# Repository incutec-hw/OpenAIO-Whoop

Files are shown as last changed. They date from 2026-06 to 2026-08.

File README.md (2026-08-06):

# OpenAIO-Whoop

Open-source whoop-class AIO board with a 25.5 x 25.5 mm mounting pattern, part of the incutec OpenDrone line. One board combines an RP2354A flight controller (LSM6DSV16X IMU, Betaflight custom target), four Bluejay (EFM8BB51) brushless ESC channels on an XR8G02M direct-drive P+N power stage, a serial ExpressLRS 2.4 GHz receiver (ESP32-C3 + SX1281) and a W25Q128JVPIQ 16 MB SPI NOR blackbox flash. Digital video only: SH1.0 6-pin HD-VTX port, no onboard analog VTX or OSD. Target class is 1S/2S whoops (65-85 mm). Designed in KiCad 10.

Full specification, part-level detail (LCSC numbers, power stage rationale, second sources) and current design state: [hardware/docs/DESIGN.md](hardware/docs/DESIGN.md).

## Status

**Prototype pending**, early design, 2026-08-05.
Forked from OpenAIO and being adapted for whoop class. FC and RX schematic sheets are imported from sibling designs and ESC parts are selected, but the ESC channel sheet and the board layout still carry the inherited donor design. Sheet-by-sheet state: [Design state](hardware/docs/DESIGN.md#design-state).

## Repository layout

| Path | Contents |
|---|---|
| `hardware/` | KiCad 10 project: top sheet, sub-sheets, project-local libraries |
| `hardware/docs/` | Design documentation ([DESIGN.md](hardware/docs/DESIGN.md), [ESC_DESIGN.md](hardware/docs/ESC_DESIGN.md), [MARKET-RESEARCH-2026-06.md](hardware/docs/MARKET-RESEARCH-2026-06.md)) |
| `libs/KiCad-Library` | Shared Incutec symbol/footprint/3D library (git submodule) |

## Design entry points

- Top schematic: `hardware/OpenAIO-Whoop.kicad_sch`
- FC sheets: `hardware/schematics/fc/` (rp2350a, power, imu, blackbox, pads; from OpenFC-Lite-Mini rev 2, no OSD sheet)
- ESC sheet: `hardware/schematics/esc/esc_channel.kicad_sch`, instantiated 4 times
- RX sheet: `hardware/schematics/elrs/elrs.kicad_sch` (OpenRX-Lite)
- Board: `hardware/OpenAIO-Whoop.kicad_pcb`

Project-local libraries: `hardware/lib.*` (FC), `hardware/whoop.*` (Bluejay ESC parts), `hardware/components.kicad_sym` with `hardware/4in1ESC.pretty` (ESC donor parts), `hardware/OpenRX-Shared.*` (RX). The project lib tables also reference the shared `Incutec` library from the `libs/KiCad-Library` submodule, used for new parts; KiCad standard libraries are the only other external references.

## Build and export

```
git clone --recursive https://github.com/incutec-hw/OpenAIO-Whoop.git
```

Open `hardware/OpenAIO-Whoop.kicad_pro` in KiCad 10. Production exports (gerbers, BOM, CPL) are generated with the [KiCad Fabrication Toolkit](https://github.com/bennymeg/Fabrication-Toolkit) plugin into `hardware/production/` (gitignored). Headless checks use `kicad-cli`:

```
kicad-cli sch erc --exit-code-violations hardware/OpenAIO-Whoop.kicad_sch
kicad-cli pcb drc --exit-code-violations hardware/OpenAIO-Whoop.kicad_pcb
```

## Manufacturing

No production exports exist yet and no hardware has been fabricated.

## Contributing

See [CONTRIBUTING.md](CONTRIBUTING.md).

## License

Hardware licensed under [CERN-OHL-S-2.0](https://ohwr.org/cern_ohl_s_v2.txt). See [LICENSE](LICENSE). Referenced firmware projects (Betaflight, Bluejay, ExpressLRS) remain under their own upstream licenses.

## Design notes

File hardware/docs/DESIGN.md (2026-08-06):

# OpenAIO-Whoop Design Notes

Detailed design description of the OpenAIO-Whoop. The design is early stage: part selection is done, the ESC schematic and the whoop board layout are not. ESC topology research and sourcing history: [ESC_DESIGN.md](ESC_DESIGN.md). Competitive landscape: [MARKET-RESEARCH-2026-06.md](MARKET-RESEARCH-2026-06.md).

## Architecture

Three stages on one board with a 25.5 x 25.5 mm mounting pattern: flight controller, 4x brushless ESC, serial ExpressLRS 2.4 GHz receiver. Target class is 1S/2S whoops, 65-85 mm. Digital video only: an SH1.0 6-pin HD-VTX port, no analog VTX or OSD hardware.

| Stage | Basis | State |
|---|---|---|
| FC | OpenFC-Lite-Mini rev 2 sheets (RP2354A) | imported |
| ESC | New design: EFM8BB51 (Bluejay BB51) + XR8G02M direct-drive P+N power stage, SiA527DJ qualified second source | parts imported, schematic not drawn |
| RX | OpenRX-Lite (ESP32-C3 + SX1281, serial ELRS) | imported |

## Design state

- Pack voltage (1S vs 2S) is undecided. On top of the locked direct-drive P+N power stage, it decides the per-phase level-shift parts (2S adds a 2N7002 level shift per phase so the P-gate can reach VBAT) and the BEC topology (1S needs a boost to feed a DJI O4 Lite properly).
- ESC power stage is decided: XR8G02M, 2 x 2 mm complementary P+N, GPIO direct drive, no gate-driver IC, honest rating ~8 A continuous / 15-20 A burst per motor. The 12 A dual-N market tier is deliberately not pursued: dual-N needs high-side drive, excluded by the no-driver constraint. Earlier candidates (AGM310MAP, AGM314MAP, N+N plus driver) are superseded; full history in [ESC_DESIGN.md](ESC_DESIGN.md).
- Blackbox: W25Q128JVPIQ 16 MB SPI NOR replaces the microSD slot and the dead BY25Q64; the blackbox sheet still shows the microSD slot until redrawn.
- The ESC channel sheet (`esc_channel.kicad_sch`, instantiated 4x) still contains the inherited AT32/AM32 donor channel from the OpenESC lineage, not the EFM8BB51 + XR8G02M design.
- The board file (`OpenAIO-Whoop.kicad_pcb`) carries the inherited OpenAIO placement and routing, not a whoop layout. Its Edge.Cuts outline is still the donor 33 x 33 mm rounded rectangle around the 25.5 x 25.5 mm hole pattern; no whoop outline has been drawn.
- The 1.8 V gyro LDO on the inherited FC sheets, NCV8187 (effectively unobtainable), is replaced by TPS7A2018 (decided, imported); the sheets still show NCV8187.

## Key parts, Bluejay ESC (`whoop` library)

| Function | Part | LCSC | Note |
|---|---|---|---|
| ESC MCU x4 | EFM8BB51F16G-C-QFN20R (8051, 50 MHz) | C6547511 | Bluejay BB51 target; not in JLC assembly lib, verify or consign |
| Power stage | XR8G02M complementary N+P, DFN2020-8 (2 x 2 mm), x3 per channel, GPIO direct drive | C42457203 | 20 V, N 15 / P 25 mOhm max at 4.5 V (spec'd to 2.5 V), ~8 A cont / 15 A+ burst per motor. Single-source brand: reel-order up front. Second source: SiA527DJ (C222486) |
| 1.8 V gyro LDO | TPS7A2018PDQNR, X2SON-4 (1 x 1 mm) | C2878130 | 75 dB PSRR at 10k-100 kHz; LCSC stock thin, consign from DigiKey |
| Blackbox flash | W25Q128JVPIQ 128 Mbit SPI NOR, WSON-8 (5 x 6 mm) | C190862 | 16 MB is the market bar; replaces dead BY25Q64 |
| RX MCU option | ESP8685H4 (ESP32-C3 die, 4 MB flash), QFN-28 (4 x 4 mm) | C4944062 | 1 mm smaller each side than ESP32-C3FH4; same ELRS targets |

## Key parts, FC and RX (inherited from sibling designs)

RP2354A, LSM6DSV16XTR, 2x LMR51430, TPS2116, LP5912, NCV8187 (superseded by TPS7A2018, see above), TF-021B microSD (superseded by W25Q128JVPIQ, see above), ESP32-C3FH4 + SX1281 + TLV75533. Full part tables are in the [OpenAIO](https://github.com/incutec-hw/OpenAIO) repo.

## Firmware targets

| Stage | Target |
|---|---|
| FC | Betaflight, derived from `OPENFC_LITE_MINI_RP2350A` (custom target) |
| ESC x4 | Bluejay BB51, 48 kHz (2S) / 96 kHz (1S), bidirectional DShot |
| RX | ExpressLRS `Unified_ESP32C3_2400_RX` (survives in ELRS 4.0 targets) |

## Market reference

Class reference board: BetaFPV Matrix 1S 3IN1 HD. Its specification, the class bar it sets, the full whoop-class table and the verified 2025-2026 trends: [MARKET-RESEARCH-2026-06.md](MARKET-RESEARCH-2026-06.md).

## Revisions

- **2026-08-04**: shared Incutec KiCad library wired in as the `libs/KiCad-Library` submodule.
- **2026-06-12**: ESC part selection: XR8G02M power stage (SiA527DJ second source), no-gate-driver topology locked, W25Q128JVPIQ blackbox flash, TPS7A2018 gyro LDO. Repo restructured under `hardware/`; FC and RX sheets imported; Bluejay part libraries and research docs added.
- **2026-06-01**: forked from OpenAIO as the whoop-class variant.

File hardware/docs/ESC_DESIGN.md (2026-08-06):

# Bluejay ESC, topology and sourcing research

Research trail behind the OpenAIO-Whoop ESC stage: what was measured, what was rejected, and why. The current decisions and their LCSC numbers live in [DESIGN.md](DESIGN.md); this file keeps the comparisons that produced them and does not restate the final part table. Competitive landscape and the class bar this research measured against: [MARKET-RESEARCH-2026-06.md](MARKET-RESEARCH-2026-06.md).

Scope of the work: rework the inherited AT32F421 / NSG2065Q ESC into a Bluejay (EFM8BB51, BB51 target) design for a 1S/2S whoop-class AIO with integrated ELRS and a digital video connector. Library import is done; no schematic or PCB work has been performed yet.

## Topology: no gate-driver IC (locked, 2026-06-12)

**The Bluejay ESC has no gate-driver IC, EFM8 GPIO direct drive only, there is no board space for one.** That locks the power stage to a complementary P+N pair per phase, because a high-side N-channel is impossible without a driver or a bootstrap. Consequences:

- 1S: clean direct drive, zero extra parts (the CrazyBee / tinyPEPPER pattern, confirmed by the teardowns below).
- 2S: the P-gate must reach VBAT (8.4 V) to turn OFF, so each phase needs a discrete level shift (2N7002, C8545, a JLC basic part, plus a pull-up: about 2 parts per phase, 24 per board). That is the only no-driver-IC option. If even that is too much board space, the design is 1S-only.
- The 12 A dual-N market tier (BetaFPV SiZ322DT boards) is off the table, because dual-N needs high-side drive. Honest rating for this topology is ~6-8 A continuous per phase, which covers 65-75 mm 1S whoops (real currents <=5 A per motor), not the 12 A spec-sheet war.

### Gate drive research that led there

Verified: small Bluejay/BLHeli_S whoop ESCs (for example **tinyPEPPER**, open hardware) drive the FET gates directly from the EFM8, with no gate-driver IC. That is correct **for 1S only**:

- At 1S (<=4.2 V) the 3.3 V GPIO can turn the high-side P-channel both ON (Vgs about -4 V) and OFF (the gate can be pulled to pack voltage). The MCU runs straight off the 1S pack.
- At 2S (8.4 V) direct drive breaks down: the P-channel source sits at 8.4 V and a 3.3 V GPIO cannot pull the gate up to 8.4 V to switch the high side **off**. tinyPEPPER author: *"For 2S one needs FET drivers and a proper voltage regulator for the CPUs."*

Open points that follow:

- At 2S the EFM8 needs its own 3.3 V regulator; it cannot run off the pack directly (abs max ~4.2 V).
- The low-side N can still be GPIO-driven through a gate resistor at 2S (source at GND, 3.3 V against Vgs(th) 1.6 V). Verify enhancement is adequate, consider a buffer if marginal.
- Pick gate resistors from Qg and the desired edge rate (tinyPEPPER reference: ~100 Ohm for ~50 nC / 500 ns).
- Rejected alternative: a proper 3-phase gate driver IC, which is what the inherited NSG2065Q did. Most robust, biggest BOM, no board space.

## What commercial whoop ESCs actually use (teardown research, verified)

- **CrazyBee F4 V2 class (5-10 A 1S, the architecture we are copying)**: 12x N+P complementary pairs marked "EGX87C" (full MPN never decoded, sold as repair parts under the marking), **driven directly by EFM8 GPIO, no driver**.
- **NewBeeDrone BLV1-4 / Hummingbird V2/V3**: the official replacement part is "N+P MOS" x12, same topology, MPN undisclosed.
- **BetaFPV F4 1S 12A (2022)**: 12x Vishay SiZ322DT dual-N 25 V PowerPAK1212 (3.3 x 3.3), EOL at DigiKey (successor SiZ350DT ~$2). Teardown identifies roughly 3-pin 0402-size parts plus 3 Schottkys and 3 bootstrap caps per motor, so the undocumented high-side drive is a **discrete bootstrap level shift per phase**: about 3 extra parts per phase, 9 per motor, 36 per board. Not for us.
- **NBD BLV5 / RaceSpec V2 "18A"**: "double N-channel", MPN undisclosed.
- **20 A+ toothpick tier**: Toshiba TPN2R203NC-class discrete N plus FD6288 drivers, that is the OpenESC-20x20 architecture, irrelevant here.
- **2025 Matrix 1S 5IN1 II (Air65 II, "12A/18A")** uses AGMSEMI **AGM210MAP, complementary P+N, GPIO direct drive: the same architecture we chose.** Datasheet verified locally: PDFN 3.3 x 3.3 (not 2 x 2; note that LCSC and BetaFPV listings say 25 V while the datasheet says **20 V**), N 10 typ / 14 max mOhm at 4.5 V (14/20 at 2.5 V), P 13 mOhm typ, Vgs(th) max 1.0 V, 25 A / 100 A pulsed, RthJC 3.5. C7431169, 10,623 stock, 20x the stock of AGM310MAP or AGM314MAP.
- Bluejay layout naming note: the middle letter (Z_**H**_30, A_**X**_5) is the MCU family (H = BB21, X = BB51), NOT the FET topology; only the deadtime digits hint at the stage.

Implications of the Matrix 1S 5IN1 II teardown:

- The flagship "12A/18A" 1S board is P+N direct drive, so our topology is the current market architecture, not the legacy one. Their 12 A claim on N 10 / P 13 mOhm dies works out to about 1.7 W per phase: spec-sheet optimistic, and consistent with our honest-rating stance.
- **AGM210MAP supersedes AGM310MAP and AGM314MAP as the AGMSEMI pick at the 3.3 x 3.3 tier** (better dies, field-proven on the Air65 II, real stock). Earmarked for the mid-tier 2S Bluejay concepts, not for this board: its 20 V rating means a 2-3S ceiling.
- Why 20-25 V parts on a 1S board? Voltage class is nearly free in trench processes; it buys avalanche margin against phase-node inductive spikes and lets one part cover 1S to 2S+ product lines. XR8G02M (20 V) follows the same logic.
- Also on that board: G473CEU6 (we use RP2354A), BB51F16G QFN-20 (the same EFM8 as ours), AT7456E analog OSD plus an RTC6705-class VTX (not applicable, we are digital-only), PUYA PY25Q128 16 MB blackbox flash, and a **2-Schottky diode-OR for 5 V/USB selection** instead of a power-mux IC. The diode-OR is a candidate to replace TPS2116 on the whoop: saves space and cost, costs ~0.3 V drop, trade accepted.

## Power stage sweep

Requirement from the layout: the package must fit a whoop board, so <=2.2 x 2.2 mm. AGM314MAP (3.3 x 3.3) is too big for this board and stays earmarked for the larger AM32 toothpick AIO. A full LCSC sweep at <=2.2 x 2.2 found **exactly one power-class complementary N+P family at 2 x 2: Diodes DMCxxxxUFDB (U-DFN2020-6)**. Everything else complementary at SOT-563 or SOT-363 is small-signal (>=350 mOhm). AGMSEMI has nothing below 3.3 x 3.3.

### Selected: XR8G02M (round 3)

**XR8G02M (XNRUSEMI, DFN2020-8L, 2 x 2)** was missed by both parametric sweeps because LCSC files it under "Single FETs". Datasheet verified against the listing:

- N: 12 typ / 15 max mOhm at 4.5 V, 16/23 at 2.5 V, Vgs(th) 0.5-1.5 V
- P: 17 typ / 25 max at 4.5 V, 24/30 at 2.5 V
- 20 V Vds (against SiA527DJ's 12 V, so proper spike margin at 1S), +/-12 V Vgs, 8 A continuous, 32 A (N) / 28 A (P) pulsed, avalanche-rated, PD 15/20 W
- Qg 15/19 nC at 10 V (roughly 6-9 nC at 3.3 V), slightly heavier gates than the alternatives. Fine at 24-48 kHz PWM with direct GPIO drive; do not run 96 kHz.
- Pinout: D1/G1/D2/G2 bottom row, S1 x2 / S2 x2 top, dual exposed pads. Die 1 is the N, die 2 is the P; verify the assignment in the schematic.
- Price $0.036-0.05, cheapest candidate by 3-6x.

It beats SiA527DJ (N 29 / P 41 max) and DMC1229UFDB (N 29 / P 61 max) on every electrical axis. **Supply is the only weakness: LCSC live stock 80 pcs, XNRUSEMI is a small single-source brand, standard reel 4000, so order or quote a reel up front** (consignment workflow accepted). SiA527DJ stays the qualified second source on its own footprint, with the AON2406 + YJQ1216A pair as the BOM-resilient fallback.

### Round 2: SiA527DJ is the dual-package ceiling

Second sweep covering Vishay PowerPAK SC-70-6, onsemi WDFN 2 x 2, Diodes 8-lead, and AOS / Toshiba / Nexperia / Chinese-brand 2 x 2-8L (DigiKey acceptable, consignment OK):

- **No <=2.3 mm complementary dual reaches N <=20 / P <=35 mOhm. The class ceiling is the Vishay SiA527DJ** (PowerPAK SC-70-6, 2.0 x 2.0 x 0.8): N 29 / P 41 mOhm max at 4.5 V, spec'd down to a 1.5 V gate, Vgs(th) <=1.0 V, +/-4.5 A continuous, 20 / -15 A pulsed, 12 V. LCSC C222486 (4.9k, ~$0.24) and DigiKey 11k, so dual-sourced. P-side 33% better than DMC1229UFDB, N-side a tie. NOT pin-compatible with U-DFN2020-6, different footprint, verify phase-leg orientation.
- Nexperia LFPAK22 is N-only (no P exists); AOS and Toshiba have no complementary part at <=2.3 mm; LCSC has zero Chinese-brand complementary duals in any 2 x 2-8L package (verified via API).
- **If Rds is the priority, the discrete pair wins decisively: AON2406** (N, 12.5 mOhm max at 4.5 V, C3277752, 6.5k stock) **+ YJQ1216A** (P, 19 max / 11 typ, C919545, 1.9k stock), both DFN2020-6, ~$0.21-0.25 per phase. That is 2.3x (N) and 3.2x (P) lower than the best dual, both spec'd at 2.5 V, and gives a true 5 A continuous per phase. Cost: 24 placements instead of 12, though total area (96 mm2) is still less than 12x AGM314MAP (131 mm2). BOM-resilient, because N and P substitutes at 2 x 2 are plentiful and independent. YJQ1216A is LCSC-only; DigiKey P alternates at 2 x 2 are thin (DMP1022UFDF, C155358, as a second source). Verify AON2406 low-Vgs behaviour (sister part AON2408, C2931064, has the documented 2.5 V spec).

All three imported into the `whoop` library (SIA527DJ-T1-GE3, AON2406, YJQ1216A); the SiA527DJ datasheet is held locally.

**Open choice if XR8G02M supply fails:** SiA527DJ dual (12 packages, simpler) against the AON2406 + YJQ1216A pair (24 packages, about half the conduction loss).

### Round 1: DMC1229UFDB-7, the fallback dual

**DMC1229UFDB-7 (C443653, U-DFN2020-6, 2.0 x 2.0 x 0.6 mm)**, imported into the `whoop` library, datasheet local.

- +/-12 V, N 29 / P 61 mOhm max at 4.5 V, spec'd down to a 1.8 V gate (true logic level, Vgs(th) max 1.0 V), so at 3.3 V worst case about N 31 / P 70 mOhm
- Id 5.6 / -3.8 A continuous, 20 / -15 A pulsed. Realistic on a dense whoop board: **~2.5 A continuous, ~5 A for seconds, 10 A+ pulses per phase**, which matches 0802/1002 motor reality (2-5 A peaks).
- Smaller and thermally better (leadless, RthJC 30) than the SOT-23-6-class "EGX87C" parts on commercial 5 A whoop boards, so not a downgrade.
- Caveat: 12 V Vds at 1S. Fine with a low-inductance layout plus per-phase ceramic bypass; watch switching spikes on the bench.
- Stock: LCSC 2,280 plus DigiKey backup; family stock swings hard, so dual-source reels.

Same-footprint variants (drop-in, U-DFN2020-6 Type B pinout): **DMC2041UFDB-7** (20 V, P 90 mOhm at 4.5 V, derate to ~2 A; LCSC 165 / DigiKey 5,840) if spike margin worries; **DMC1030UFDB-7** (best silicon: N 17 typ / P 59 max, IDM 35 A, RthJC 18; LCSC 0 / DigiKey 2,784, prototype via DigiKey).

### Superseded: the AGMSEMI 3.3 x 3.3 line

The first pass scoped the ESC around **AGM310MAP** (C5184858, PowerDI3333-8), imported into the `whoop` library on `POWERDI3333-8_L3.3-W3.3-P0.65-LS3.4-BL-EP_UXC`. Confirmed topology from the AGMSEMI datasheet, kept here because the pinout is shared across the family:

- Complementary pair: 1x P-channel (high side) + 1x N-channel (low side), common drain.
- 30 V Vds. N: 20 A, Rds(on) 11 mOhm at 10 V, Qg 16 nC. P: 18 A, Rds(on) 19 mOhm at 10 V, Qg 45 nC. Vgs(th): N 1.6 V, P 1.5 V.
- Pinout: FET1 = G2/D8/S1, FET2 = G4/D5/S3. Tie the two drains (D5, D8) for the phase output; P source to VBAT, N source to GND.
- Massively overspec for 2S (used at about 25% of Vds), so oversized but cool-running.

Why it was dropped:

- **Thermal, at the 12 A class floor.** P-channel Rds(on) is 19 mOhm. At 12 A phase current with ~50% high-side conduction, P = 12^2 x 0.019 x 0.5 = about **1.4 W per phase high side** (4.1 W total high side at full load) in 3.3 x 3.3 mm packages on a ~25 mm board. The complementary P+N topology is comfortable in the **5-8 A class**, marginal at 10 A, and not credible at 12 A continuous / 18 A burst.
- **Supply.** 166 JLC assembly / 515 LCSC retail at 12 per board is about 42 boards total, a production blocker.
- **Package.** 3.3 x 3.3 is too big for a whoop board.

**AGM314MAP (C17701056)** replaced it first: pinout verified IDENTICAL to AGM310MAP from both datasheets (Pin1 = S1, G1/S2/G2 bottom row, D1/D2 pads; FET1 = N 30 V / 10 mOhm at 10 V / 30 A, FET2 = P -30 V / 18.5 mOhm at 10 V / -20 A), same PDFN 3.3 x 3.3 package, strictly better dies, ~3k LCSC stock (against 166-515), **$0.074 at 500, 35% cheaper**. Imported into the `whoop` library. Caveat for direct 3.3 V drive: the datasheet specs Rds at 10 V and 4.5 V only, N 16 mOhm typ / P 27 mOhm typ at 4.5 V, and Vgs(th) max 2.2 V leaves only ~1.1 V of overdrive worst case at 3.3 V. **Bench-verify Rds and switching at a 3.3 V gate on a 1S pack** before committing to this part. (That is the same regime every CrazyBee-class board operates in.)

AGM210MAP then superseded both, see the Matrix teardown above. Hedges recorded at the time, still valid for anything built on the 3.3 x 3.3 tier:

- Diodes **DMC3025LDV-13**, same PowerDI3333-8 footprint class, Western brand, DigiKey 5.7k at $0.25/1k. But Vgs(th) 2.4 V and Rds spec'd at 4.5 V make it **not credible at 3.3 V direct drive**; it is a 2S-with-level-shift second source only.
- Discrete pair on a dual-pad footprint: AGM30P08AP (P, 11.5 mOhm at 4.5 V, 6k stock) + AGM310AS (N, DFN 2 x 2, $0.048) if the AGMSEMI duals dry up.
- AGM318MAP and AGM312MAP exist in the same package but are worse and lower-stock, ignore them.

### Rejected topology: N+N plus driver

N+N FETs with a 3-phase half-bridge driver per channel is what the 12 A+ commercial boards do (NBD "double-NMOS"). Driver candidates were the FD6288Q family clones (6288Q-MNS and similar, proven in the OpenESC-20x20 lineage). They need a >=10 V gate supply, so 2S-only or a small boost. Excluded by the no-driver-IC decision above. A hybrid (low-side N on direct GPIO, high-side N on a bootstrap driver) was considered and excluded for the same reason.

## Rating: honest numbers against the market

Market tier marketing is 12 A continuous / 18 A burst (BetaFPV Matrix dual-N SiZ322DT at about 5.3 + 6.35 mOhm, so roughly 0.84 W per phase at 12 A, only reachable with dual-N plus high-side drive, which the no-driver constraint excludes).

XR8G02M direct-drive P+N at a ~3.3 V gate (estimated ~14/20 mOhm typ) gives about 17 mOhm average conduction: 1.1 W per phase at 8 A, 2.4 W at 12 A.

**Honest spec target: ~8 A continuous / 15-20 A burst per motor** (IDM 32/28 A). Real 1S whoop flight currents are 2-5 A with brief 8-10 A punch-outs, so in practice this matches what "12 A" boards sustain on 65-75 mm 1S. Publish the measured rating, not the marketing one.

Package allocation across the family: **2 x 2 XR8G02M is this whoop board**; the AM32 toothpick AIO keeps its own 3.3 x 3.3 N-FET plus driver stage (DOY180N03T + NSG2065Q from OpenESC-20x20); **AGM210MAP** (3.3 x 3.3 complementary) is reserved for the mid-tier 2S Bluejay concepts (OpenAIO-Lite-HD/Analog), where its 20 V rating gives a 2-3S ceiling.

## Other stage decisions

**Blackbox flash.** The inherited TF-021B microSD slot goes, replaced by SPI NOR on a free RP2350 SPI bus; remove the slot and its associated parts. BY25Q64ESCIG (C50176394, 64 Mbit, DFN-8 3 x 2) was the first pick and is dead at retail (LCSC stock 1), so it is superseded by W25Q128JVPIQ. Sourcing rationale for the replacement: 16 MB is the market bar and the same capacity BetaFPV ships, and WSON-8 5 x 6 is the smallest stocked 3.3 V 128 Mbit package, because the 2 x 3 DFN class tops out at 64 Mbit with everything either dead or 1.8 V (W25Q64JV and ZD25Q64 were the 2 x 3 candidates checked). Stock at selection: 6.4k in WSON-8 plus 110k in the SOIC variant. Still a smaller package than BetaFPV's SOP-8. Part numbers in [DESIGN.md](DESIGN.md).

**RX MCU density option.** ESP8685H4 is the ESP32-C3 die with in-package 4 MB flash in a QFN-28 4 x 4, against the QFN-32 5 x 5 of the ESP32-C3FH4: the ESP8285 analog for the C3 generation. It runs the same ELRS ESP32-C3 targets and OpenRX already had the datasheet on file. Costs a new footprint and fewer GPIO, so the RX section needs a relayout. Stock at selection: 872 in the JLC assembly library. Imported into the `whoop` library.

**Current sense.** Drop the inherited 4x INA186 per-channel scheme on the top sheet. Bluejay commutates sensorless (BEMF), so per-phase sensing is not needed. If telemetry is wanted, use one total-current shunt on the pack return into a single amp into an FC ADC. Shunt candidate: 1 mOhm 1206 (C7467246); 0.625 W at 25 A is 63% of the 1 W rating, so use a 2010 WSLP for margin.

**Motor connectors.** JST/Molex 1.25 mm 3-pin is the canonical whoop motor plug: C293630 (Molex PicoBlade), with the C3029360 clone at a third of the price.

**HD video connector.** Add a standard HD-VTX connector, SH1.0 6-pin on the DJI O4 pinout. Pinout and BEC requirements: [MARKET-RESEARCH-2026-06.md](MARKET-RESEARCH-2026-06.md).

**Firmware.** EFM8BB51 is a BB51 target. Classic BLHeli_S predates BB51 and the Bluejay fork adds it, so the ESC ships Bluejay pre-flashed, never stock BLHeli_S.

**1.8 V gyro LDO (family-wide).** TPS7A2018PDQNR was chosen over LP5912-1.8 on actual PSRR curves: 75 dB spec'd at both 10 kHz and 100 kHz, where LP5912 dips to about 58 dB right in the 20-30 kHz MEMS gyro drive band, and the original NCV8187 collapses to about 35 dB at 300 kHz. Noise 7-10 uVrms. Trade-offs: the PG pin is lost (D8 LED net) and it is a new footprint, both accepted, since a re-route was needed anyway. Keep a ferrite or RC pole ahead of the LDO for the ~1 MHz buck band, where every candidate sits at 45-50 dB. Supply at selection: only 42 pcs LCSC retail against 25k at DigiKey at $0.136, so consign. The SOT-23-5 DBV part (C963430, 25k LCSC stock) is the large-package alternate. Imported into the `whoop` library here and into the `imports` library in OpenAIO; full comparison table in the OpenAIO repo, `docs/SOURCING-2026-06.md`.

## Sourcing snapshot (LCSC, 2026-06-12)

Point-in-time figures from the selection pass. The AGM310MAP and BY25Q64ESCIG rows are the reason those two parts were dropped; current parts and their stock position are in [DESIGN.md](DESIGN.md).

| Part | LCSC | JLC asm stock | LCSC retail | Verdict |
|---|---|---|---|---|
| EFM8BB51F16G-C-QFN20R | C6547511 | **not in JLC lib** | 17,124 | LCSC plentiful; verify JLCPCB assembly availability or consign |
| EFM8BB51F16I (alt) | C3232998 | 119 | 0 | G-grade is the buy |
| AGM310MAP | C5184858 | 166 | 515 | **Production blocker**, 12 per board is ~42 boards total. Second-source or change topology |
| BY25Q64ESCIG | C50176394 | 305 | **1** | Dead at retail. Swap to a stocked NOR part (W25Q64JV / ZD25Q64 class was checked first) |
| 2N7002 (level shift) | C8545 | **basic part** | 1.8M | OK |
| 1 mOhm 1206 shunt | C7467246 | - | 96k | OK (0.625 W at 25 A is 63% of the 1 W rating; 2010 WSLP for margin) |
| Motor plug 1.25 mm 3P | C293630 (Molex PicoBlade) | - | 29k | Canonical whoop motor connector; C3029360 clone at a third the price |

Whole-family supply flag (affects the FC sheets inherited from OpenFC-Lite-Mini): **NCV8187AMT180TAG (1.8 V gyro LDO, C893189) is effectively unobtainable** (62 JLC / 19 LCSC). Replacement decided, see the LDO note above.

## Library import notes

Symbols in `hardware/whoop.kicad_sym`, footprints in `hardware/whoop.pretty/`, 3D models in `hardware/whoop.3dshapes/`, all under the `whoop` lib-table nickname. 3D-model paths are `${KIPRJMOD}`-relative. The library holds the current picks alongside the second sources and the superseded candidates discussed above, so treat [DESIGN.md](DESIGN.md) as the list of what is actually current.

EFM8 grade: the imported symbol is `EFM8BB51F16G-C-QFN20R` on `QFN-20_L3.0-W3.0-P0.50-TL-EP1.7_SILICON_C8051F85X`, the **G** grade (commercial, -40 to +85 C). The I-grade `EFM8BB51F16I-C-QFN20R` (C3232998) is the wider-temp, pin-identical alternate if the G grade runs short.

## Open items for the first whoop spin

- [ ] Lock the pack voltage: 1S-only or 1S/2S. It gates the per-phase level shift and the BEC topology.
- [ ] Confirm the XR8G02M die assignment in the schematic: die 1 = N (low side), die 2 = P (high side).
- [ ] At 2S, power the EFM8 from a regulated 3.3 V rail; decoupling per datasheet, C2 debug header exposed.
- [ ] Bulk and phase caps rated for the pack voltage (>=16 V at 2S).
- [ ] Reverse-polarity protection on the pack input.
- [ ] Bluejay signal pins, one per channel, routed to the FC.

## Sources

- tinyPEPPER (fishpepper): https://fishpepper.de/projects/tinypepper/
- ckflight BLHeli_S ESC hardware: https://ckflight.github.io/ESC_BLDC_HARDWARE/
- BLHeli_S (bitdump): https://github.com/bitdump/BLHeli
- brushlesswhoop.com, anatomy of an all-in-one FC: https://brushlesswhoop.com/anatomy-of-an-all-in-one-fc/
- AGM310MAP: LCSC C5184858 (AGMSEMI), https://www.lcsc.com/product-detail/C5184858.html

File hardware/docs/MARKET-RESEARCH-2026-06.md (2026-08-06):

# FPV AIO Competitive Landscape, June 2026

Research for the two OpenDrone AIOs: **OpenAIO** (toothpick, 25.5×25.5, 6S, AM32, onboard ELRS) and **OpenAIO-Whoop** (1-2S, Bluejay, digital-only). Web research with adversarial verification against primary sources (DJI manuals, GitHub APIs, manufacturer manuals), 2026-06-12.

## Toothpick class (25.5×25.5, 3-6S, 30-55 A)

| Board | MCU / Gyro | ESC | RX | Blackbox | Weight | Price |
|---|---|---|---|---|---|---|
| **HDZero Gamma 45A** | G473 /, | 45A/60A AM32, 3-6S | **onboard serial ELRS 2.4G** | - | 8.4 g | $89.99 |
| Airbot Fenix G4 | G473 / ICM-42688P | 35A/45A AM32 (QF32MTF4AK8U7 = AT32F421+ID6288 chiplet) | none | 16 MB | - | $89.99 |
| Holybro Kakute AIO G473 | G473 / ICM-42688P | 35A AM32, 4× discrete MCUs | none | 16 MB | 7.5 g | ~$90 |
| Flywoo GOKU GN745 V3 | F745 / MPU6000 or ICM42688 | 45A AM32 | none (pads) | 16 MB | 9.4 g | $89.99 |
| GEPRC TAKER F722 45A | F722 / ICM-42688P | 45A/55A BLHeli_32 (EOL fw) | none | 16 MB | 9.2 g | $79.99 |
| iFlight BLITZ Whoop F7 55A | F745 / ICM42688 or BMI270 | 55A/65A Bluejay | none | 16 MB | 10.5 g | $116-141 |
| Foxeer Reaper AIO V4 | F745 / MPU6000 | 45A/50A BLHeli_S (Bluejay-flashable) | none | 16 Mb | 8.6 g | $99.99 |
| BetaFPV F722 35A V2 | F722 / ICM42688 | 35A/40A BLHeli_32 on AT32F421 | none | - | ~7 g | $51-114 |
| SpeedyBee F745 35A | F745 / MPU6000 | 35A/45A BLHeli_S | none | 8 MB | 10.1 g | $115.99 |
| Diatone Mamba MK5 G4 | G473 / IIM-42652 | 40A/45A BLHeli_32 | none | - | - | $79.99 |
| HGLRC Specter 25A | F722 / MPU6000 | 25A Bluejay | none | 16 MB | 12.05 g | - |

**Class structure mid-2026:** converged on G4/F7 FC + AT32F421-class ESC MCUs running AM32, 35-45 A, 25.5×25.5 Φ3 mm + M2 grommets, 16 MB flash, ICM-42688P, dual 5V/9-10V BEC, $80-100. Legacy boards stranded on EOL BLHeli_32 or 8-bit BLHeli_S.

**Direct competitor for OpenAIO: HDZero Gamma 45A**, the only 6S AIO with onboard serial ELRS. Digital-HD-only, single board, closed source, G473. OpenAIO's differentiators against it: analog PIO-OSD option, microSD blackbox (nobody has SD in class), open hardware, RP2350 (also a platform-maturity risk).

## Whoop class (1-2S)

| Board | Mount | MCU / Gyro | ESC | RX | VTX | Weight | Price |
|---|---|---|---|---|---|---|---|
| BetaFPV Air 5in1 (Air65/75) | 26×26 M1.4 | G473 / ICM42688P | 5A BB51 Bluejay 96k | serial ELRS | 400 mW analog | 2.9 g | $44.99 |
| **BetaFPV Matrix 1S 5IN1 II** | 26×26 | G473 / ICM42688P | **12A/18A BB51 Bluejay** | serial ELRS | 400 mW | ~3.5 g | $54.99 |
| **BetaFPV Matrix 1S 3IN1 HD** | 26×26 | G473 / ICM42688P | 12A/18A Bluejay | serial ELRS | **none, SH1.0 6-pin O4 port, 5V/3A BEC** | 3.2 g | ~$50 |
| BetaFPV F4 2-3S 20A (Pavo Pico) | 26×26 | F405 / ICM42688P | 20A/25A Bluejay | serial ELRS | none; 9V/2A + 5V/3A, O4 plug | 5.6 g | $54.99 |
| Happymodel X12 / Pro | 25.5×25.5 | F411 / lottery | 12A/15A | SPI / serial (Pro) | OpenVTX 400 mW | 5.1 g | $45-75 |
| Happymodel X14 | 25.5×25.5 | **G473 / LSM6DSV16X** | 12A/15A Bluejay | serial ELRS + WiFi | OpenVTX 400 mW | ~5 g | - |
| NewBeeDrone BeeBrain BLV5 | 25.5×25.5 | G474 / MPU6000 | **18A double-NMOS** Bluejay | serial ELRS **diversity** + TCXO | 400 mW | 5.8 g | $99 |
| NBD Hummingbird RaceSpec V2 | 25.5×25.5 | AT32F435 / ICM42688 | 18A Bluejay | serial ELRS | 400 mW | 4.71 g | $59.99 |
| GEPRC TAKER F411-12A-E | 25.5×25.5 M2 | F411 / ICM42688P | 12A/13A | serial ELRS | none | 4.2 g | $59.99 |
| Flywoo GOKU Versatile F405 | 25.5×25.5 | F405 / ICM42688 + baro | 12A Bluejay | serial ELRS | 400 mW | 4.6 g | $125.99 |

Notes: BetaFPV FC mount stays 26×26 M1.4 through the Matrix II generation (verified); everyone else is 25.5×25.5. Reference target for OpenAIO-Whoop: **Matrix 1S 3IN1 HD**.

## User pain points (ranked)

1. **SPI ELRS = designed-in obsolescence**, version-locked to BF, ELRS-4 incompatible today. Every 2024+ design is serial.
2. **F411 UART starvation**, structural reason F411 AIOs are legacy; vendors mislabel softserial as "FULL UARTS".
3. **Lifted motor/battery pads** during repair, mitigations users praise: through-hole-reinforced pads, motor plugs, big thermal-relieved battery pads.
4. **ESC burnout totals the whole AIO**, core economic argument against integration; per-channel SWD rescue pads help.
5. **O4-Lite-on-1S brownouts**, an entire aftermarket boost-BEC market exists (Flywoo O4 1S module, Fractal Boostybaby).
6. **Current sensing absent (1S) or miscalibrated** (factory scale off 2×).
7. **No/undersized blackbox**, 8 MB ≈ one flight; 16 MB is the bare minimum for tuning.
8. **USB ripping off**, anchor it through-hole, keep clear of frame rails.
9. **Betaflight target abandonment** + silent hardware revisions ("gyro lottery").
10. **Connector chaos**, same shells, different pinouts; silkscreen rail voltages at every plug.
11. **Mounting/grommet chaos**, 25.5/26/26.5 + M1.4/M2 mix; size holes to accept both grommet types.
12. **Zero open documentation**, no vendor publishes schematics.

## Verified trends 2025-2026

- 1S stays the 65/75 mm standard; 2S is the 85 mm tier. ESC headroom moved 5A → 12A/18A-peak even on 65 mm 1S. **12 A is the new whoop floor.**
- Digital-only "3in1/HD" whoop boards are the inflection. O4 Air Unit Lite: 6-pin SH1.0 (VCC/GND/RX/TX/GND/SBUS), no solder pads, 3.7-13.2 V, ~6 W @ 700 mW; DJI recommends ≥10 W BEC (5V/2A class) for the Lite.
- **ELRS 4.0.0** (2026-02-06): OTA-incompatible with 3.x, STM32 RX dropped; `Unified_ESP32C3_2400_RX` survives in 4.0 targets (verified).
- **BLHeli_32 dead** (June 2024). AM32 owns 32-bit; Bluejay on EFM8 BB51 (48/96 kHz) owns sub-20A whoop tier.
- **Betaflight on RP2350**: landed in 2025.12; PIO bidir DShot + PIO UARTs merged; open issues on I2C/SPI and PWM. Budget bring-up time; pin to a tested release.
- Gyros: ICM-42688-P mainstream; **LSM6DSV16X now shipping on Happymodel latest revs**, validates the family gyro choice.
- **Open-source landscape effectively empty**, no open-hardware Betaflight AIO has shipped. First-mover position intact for both boards.

## Conventions / targets

- Battery 1S: BT2.0 (9 A cont) or GNB A30; PH2.0 legacy; XT30 at 2S+. Soldered pigtail to pads, not board socket.
- Motor plugs: JST/Molex 1.25 mm 3-pin standard (PicoBlade).
- Weight bars: 1S AIO 2.9-3.6 g; 2S 12-20A ≈ 5-6 g; 6S 35-45A AIO 7.5-10 g (Gamma 8.4 g → OpenAIO stack should target ≤9 g combined).
- BF config: ship measured current-sensor scale + vbat_scale in the target config.h.
- Price bands: toothpick AM32 AIO $80-100; 1S serial-ELRS AIO $45-75; premium (diversity/18A) $99.

## Differentiation summary

**OpenAIO (vs HDZero Gamma):** open hardware + published schematics/repair diagrams, microSD blackbox, analog OSD option, honest measured current ratings, per-channel SWD rescue pads, maintained BF target every release cycle.

**OpenAIO-Whoop (vs Matrix 3IN1 HD):** open hardware, 16 MB (128 Mbit) blackbox flash (most 1S boards have none), real shunt + published current scale, ELRS antenna options, guaranteed-updated target. Class bar to meet: Bluejay BB51, 5V/3A holding to 2.8 Vin, SH1.0 6-pin O4 port, 25.5×25.5 mount, ≤3.5 g. On ESC current the class bar is 12 A; we deliberately publish ~8 A cont / 15-20 A burst per motor instead, because the no-gate-driver topology cannot reach 12 A honestly, see [DESIGN.md](DESIGN.md).

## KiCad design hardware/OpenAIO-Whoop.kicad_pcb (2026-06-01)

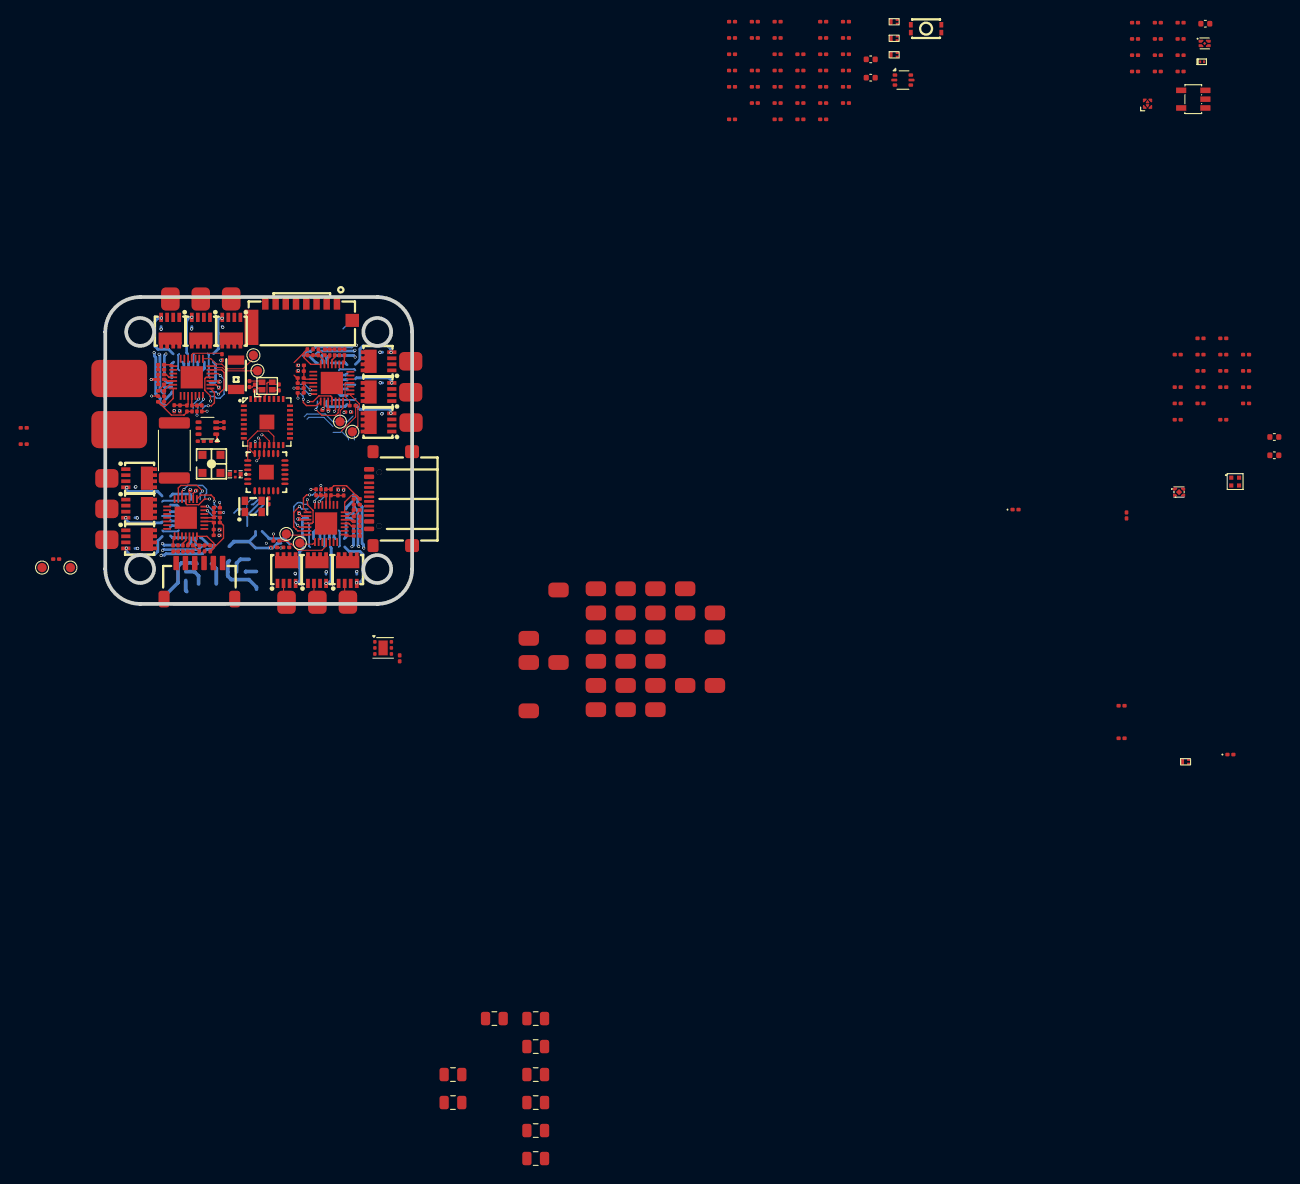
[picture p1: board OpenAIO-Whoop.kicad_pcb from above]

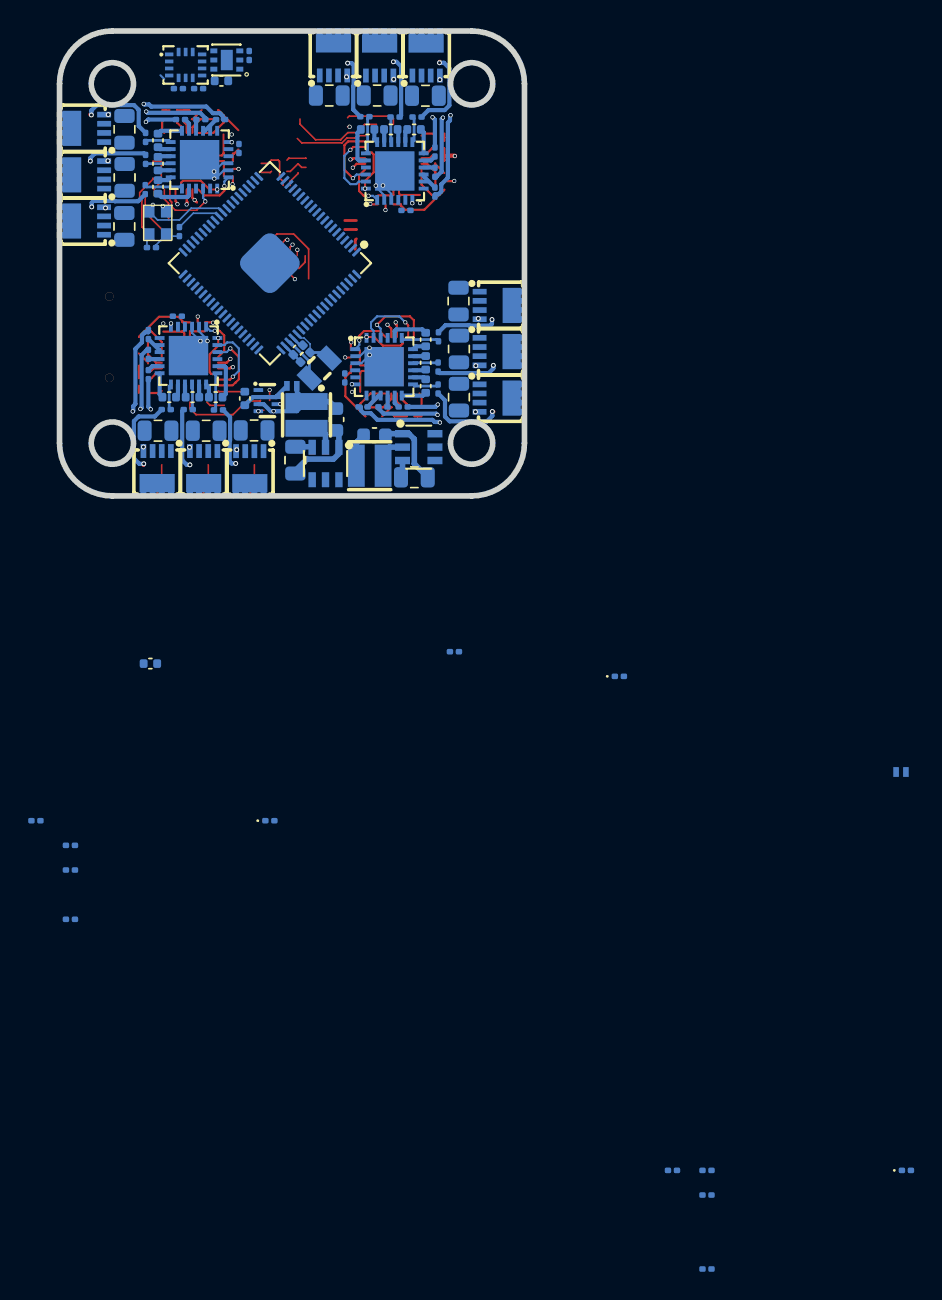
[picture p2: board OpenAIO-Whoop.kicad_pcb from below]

Board: 6 copper layers, 33.0 x 33.0 mm, 360 parts (106 on the bottom side), 247 nets.

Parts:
AE1: 2450AT18A100E; ANT-SMD_L3.2-W1.6
AE2: 47948-0001; ANT-SMD_47948-0001
C1, C2, C3, C4, C5, C6, C7, C8, C9, C10, C11, C12, C13, C14, C15, C17, C18, C19, C20, C21, C22: 10uF; C_0805_2012Metric
C16, C23, C45, C46, C47, C51, C69, C70, C71, C73, C75, C76, C77, C78, C81, C82, C85, C86, C87, C91, C92, C93, C94, C98, C99, C100, C101, C105: 100nF; C_0201_0603Metric
C24, C25, C26, C27, C28, C30, C31, C32, C34, C35, C36, C38, C40, C43, C52, C53, C56, C57, C61, C62, C107, C109, C110, C111: 100n; C_0201_0603Metric
C29, C33: 20p; C_0201_0603Metric
C39, C41, C42, C44, C60: 4.7uF; C_0402_1005Metric
C48, C49, C50, C88, C89, C90, C95, C96, C97, C102, C103, C104: 100nF; C_0402_1005Metric
C54, C55: 4.7uF 50v; C_0805_2012Metric
C58, C59: 22uF; C_0603_1608Metric
C63, C64: 22uF; C_0402_1005Metric
C65, C67: 18pF; C_0201_0603Metric
C66, C68, C74, C79: 1uF; C_0201_0603Metric
C72, C80: 10uF; C_0402_1005Metric
C83: 1nF; C_0201_0603Metric
C84: 470nF; C_0201_0603Metric
C106: 470p; C_0201_0603Metric
C108: 1uF; C_0402_1005Metric
Card1: TF-021B-H265; TF-SMD_TF-021B-H265
D1: USBLC6-2P6; SOT-666
D2, D4, D5, D7, D8: LED_1_Green; LED_0201_0603Metric
D3, D6: RB161QS-40_C28646385; SOD-882_L1.0-W0.6-RD
D9: XL-1010RGBC-WS2812B; LED-SMD_4P-L1.0-W1.0-TL_XL-1010RGBC-WS2812B
D10: SDM02U30LP3-7B; X3-DFN0603-2_L0.6-W0.3-RD
FB1, FB2, FB3, FB4: BLM03HD331SN1D; L_0201_0603Metric
FL1: 2450FM07D0034T; FILTER-SMD_4P-L1.0-W0.5-L
J2, J4, J6, J7, J10, J13, J14, J17, J18, J19, J20, J21, J22, J23, J24, J25, J26, J27, J28, J29, J30, J31, J32, J33, J34, J35, J37, J38, J39: 5V; small_pad
J40, J42, J43, J44, J45, J46, J47, J48, J49, J50, J51, J52: 5V; MotorPad
J41, J53: 5V; BatteryPad
L1: AOTA-B201610S3R3-101-T; IND-SMD_L2.0-W1.6_AOTA-B201610S3R3-101-T
L2: XRTC303020D4R7MBCA; IND-SMD_L3.0-W3.0_AFE303020S
L3: FTC303020D100MBCA; IND-SMD_L3.0-W3.0_AFE303020S
L4: 24nH; L_0201_0603Metric
OSC1: OW7EL89CENUNFAYLC-52M; OSC-SMD_4P-L2.0-W1.6-BL_TXC_7Z
Q1, Q2, Q3, Q10: DMN1150UFB-7B; DFN-3L_L1.0-W0.6-P0.65-BR
Q4, Q5, Q6, Q7, Q8, Q9, Q11, Q12, Q13, Q14, Q15, Q16, Q17, Q18, Q19, Q20, Q21, Q22, Q23, Q24, Q25, Q26, Q27, Q28: SP40N03GNJ; POWERPAK-1212-8_L3.0-W3.0-P0.65-LS3.3-BL
R1, R36, R39, R42, R69, R72, R75, R87, R90, R93, R105, R108, R111: 1k; C_0201_0603Metric
R2, R20, R22, R44, R46, R48: 100k; R_0201_0603Metric
R3, R9, R10, R14, R23, R52, R55, R56, R57, R58, R121: 10k; R_0201_0603Metric
R4, R5: 5.1k; R_0201_0603Metric
R6, R18, R19: 1k; R_0201_0603Metric
R8, R25, R51, R54: 200R; R_0201_0603Metric
R11, R12, R13, R15, R53: 30R; R_0201_0603Metric
R16, R17, R21, R24: 2.2k; R_0201_0603Metric
R26, R27, R31, R32, R33, R34, R59, R60, R64, R65, R66, R67, R77, R78, R82, R83, R84, R85, R95, R96, R100, R101, R102, R103: 15R; C_0201_0603Metric
R28, R29, R35, R37, R38, R40, R41, R43, R61, R62, R68, R70, R71, R73, R74, R76, R79, R80, R86, R88, R89, R91, R92, R94, R97, R98, R104, R106, R107, R109, R110, R112: 10k; C_0201_0603Metric
R30, R63, R81, R99: 220R; R_0201_0603Metric
R45: 39k; R_0201_0603Metric
R47: 6.8k; R_0201_0603Metric
R49: 13.7k; R_0201_0603Metric
R50, R118, R119: 470R; R_0201_0603Metric
R113, R120: 75R; R_0201_0603Metric
R114: 3.9k; R_0201_0603Metric
R115: 12k; R_0201_0603Metric
R116: 1.4k; R_0201_0603Metric
R117: 680R; R_0201_0603Metric
Rsense1: 0.2mR; R_2512_6332Metric
TP1, TP2, TP3, TP4, TP5, TP6, TP7, TP8: TestPoint; TestPoint_Pad_D1.0mm
U1: INA186A3IDCKR; SOT-363_SC-70-6
U2: TS2306A 240GF MSM 9_C2976675; SW-SMD_4P-L3.0-W2.0-P0.85-LS3.5
U3: RP2354B_C39843328; QFN-80_L10.0-W10.0-P0.40-TL-EP3.4
U4, U16, U18, U20: AT32F421G8U7; QFN-28_L4.0-W4.0-P0.40-TL-EP2.4
U5, U17, U19, U21: NSG2065Q; QFN-24_L4.0-W4.0-P0.50-TL-EP2.8
U6: LSM6DSV16XTR; LGA-14_L3.0-W2.5-P0.50-BR
U7, U8: LMR51420YFDDCR; SOT-23-6_L2.9-W1.6-P0.95-LS2.9-BL__lib
U9: TPS2116DRLR; SOT-583-8_L2.1-W1.6-P0.50-LS1.6-BL
U10: NCV8187AMT180TAG; WDFN-6_L2.0-W2.0-P0.65-BL-EP
U11: LP5912-3.3DRVR; WSON-6-1EP_2x2mm_P0.65mm_EP1x1.6mm
U12: SM06B-SRSS-TB(LF)(SN); CONN-SMD_SM06B-SRSS-TB-LF-SN
U13: ESP32-C3FH4; QFN-32_L5.0-W5.0-P0.50-TL-EP3.7
U14: TLV75533PDQNR; X2SON-4_L1.0-W1.0-P0.65-TL-EP
U15: SX1281IMLTRT; QFN-24_L4.0-W4.0-P0.50-TL-EP2.6
U22: SN74LVC1G3157DTBR; X2SON-6_L1.0-W0.8-BL
U23: TLV9061IDPWR; X2SON-4_L0.8-W0.8-P0.48-TL-DPW
U24: TLV3201AIDBVR; SOT-23-5_L3.0-W1.7-P0.95-LS2.8-BR
USB1: TYPE-C 16P QTWT; USB-TYPE-C-SMD_TYPE-C-16P-QTWT
X1: XTM25012000JT00351001; CRYSTAL-SMD_4P-L2.5-W2.0-BL-A
X2: CJ17-400001010B20; CRYSTAL-SMD_4P-L1.6-W1.2-BL

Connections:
+1.1V: C24.1, C25.1, C26.1, C41.1, L1.1, U3.10 (DVDD), U3.32 (DVDD), U3.51 (DVDD), U3.65 (VREG_FB)
+1.8V_GYRO: C52.1, C63.1, U6.8 (Vdd), U10.5 (SNS), U10.6 (OUT)
+3.3V: C28.1, C30.1, C31.1, C32.1, C34.1, C35.1, C36.1, C38.1, C39.1, C40.1, C53.1, C64.1, C107.1, C109.1, C110.1, C111.1, Card1.4 (VDD), J20.1 (Pin_1_1), Q3.1 (G), R8.1, R9.1, R13.1, R14.2, R16.1, R17.2, R21.1, R23.2, R53.1, R115.2, R121.1, U3.5 (IOVDD), U3.15 (IOVDD), U3.24 (IOVDD), U3.29 (IOVDD), U3.41 (IOVDD), U3.50 (IOVDD), U3.60 (IOVDD), U3.64 (VREG_VIN), U3.68 (USB_OTP_VDD), U3.69 (QSPI_IOVDD), U3.76 (IOVDD), U6.5 (Vdd_IO), U11.1 (OUT), U22.5 (VCC), U23.5 (V+), U24.5 (VCC)
+3V3: C16.1, C45.1, C46.1, C68.1, C69.1, C70.1, C73.1, C75.1, C76.1, C77.1, C78.1, C79.1, C80.1, C81.1, C82.1, C85.1, C86.1, C92.1, C93.1, C99.1, C100.1, FB1.1, FB2.1, FB3.1, FB4.1, OSC1.4 (VDD), R28.2, R55.1, R56.1, R57.1, R58.1, R61.2, R79.2, R97.2, U1.3 (VS), U4.17 (VDD), U13.2 (VDD3P3), U13.3 (VDD3P3), U13.11 (VDD3P3_RTC), U13.17 (VDD3P3_CPU), U13.18 (VDD_SPI), U13.31 (VDDA), U13.32 (VDDA), U14.1 (OUT), U15.2 (VDD_IN), U15.11 (VBAT_IO), U15.15 (VBAT), U16.17 (VDD), U18.17 (VDD), U20.17 (VDD)
+5V: C60.1, C61.1, C62.1, C71.1, C72.1, C74.1, D3.1 (C), D8.2 (A), D9.2 (VDD), J2.1 (Pin_1_1), J14.1 (Pin_1_1), J17.1 (Pin_1_1), J21.1 (Pin_1_1), J26.1 (Pin_1_1), J32.1 (Pin_1_1), R24.1, R52.2, U9.2 (VOUT), U9.7 (VOUT), U10.1 (IN), U10.2 (EN), U11.4 (EN), U11.6 (IN), U14.3 (EN), U14.4 (IN)
+5V_BUCK: C59.1, D3.2 (A), L3.2, R44.2, R48.2, R51.1, U9.3 (VIN1), U9.5 (MODE)
+5V_USB: D1.5, U9.6 (VIN2), USB1.A4 (VBUS), USB1.A9 (VBUS)
+8V: C51.1, C91.1, C98.1, C105.1, U5.4 (VCC), U17.4 (VCC), U19.4 (VCC), U21.4 (VCC)
+10V: C58.1, J25.1 (Pin_1_1), J30.1 (Pin_1_1), L2.2, R46.2, R50.1, U12.1
+BATT: C1.1, C2.1, C3.1, C4.1, C5.1, C6.1, C7.1, C8.1, C9.1, C10.1, C11.1, C12.1, C13.1, C14.1, C15.1, C17.1, C18.1, C19.1, C20.1, C21.1, C22.1, C54.1, C55.1, D6.1 (C), Q4.3 (D), Q6.3 (D), Q8.3 (D), Q11.3 (D), Q13.3 (D), Q15.3 (D), Q17.3 (D), Q19.3 (D), Q21.3 (D), Q23.3 (D), Q25.3 (D), Q27.3 (D), R2.1, Rsense1.2, U1.5 (-IN), U7.3 (VIN), U8.3 (VIN), U8.5 (EN)
/BLACKBOX/FLASH_CS: Card1.2 (CD/DAT3), R121.2, U3.57 (GPIO46_ADC6)
/BLACKBOX/SPI1.MISO: Card1.7 (DAT0), U3.55 (GPIO44_ADC4)
/BLACKBOX/SPI1.MOSI: Card1.3 (CMD), U3.54 (GPIO43_ADC3)
/BLACKBOX/SPI1.SCK: Card1.5 (CLX), U3.53 (GPIO42_ADC2)
/CSA+: J41.1 (Pin_1_1), Rsense1.1, U1.4 (+IN)
/CURR: C23.1, R1.1, U3.49 (GPIO40_ADC0)
/ELRS/BUSY: U13.8 (GPIO3), U15.7 (BUSY)
/ELRS/CHIP_BOOT: R58.2, U3.26 (GPIO25), U13.15 (GPIO9)
/ELRS/CHIP_EN: C66.1, R55.2, U3.25 (GPIO24), U13.7 (CHIP_EN)
/ELRS/DIO1: U13.10 (MTDI), U15.8 (DIO1)
/ELRS/LED: D9.4 (DIN), U13.16 (GPIO10)
/ELRS/MISO: U13.12 (MTCK), U15.16 (MISO_TX)
/ELRS/MOSI: U13.13 (MTDO), U15.17 (MOSI_RX)
/ELRS/NSS: R57.2, U13.14 (GPIO8), U15.19 (NSS_CTS)
/ELRS/RST: R56.2, U13.6 (GPIO2), U15.3 (NRESET)
/ELRS/SCK: U13.9 (MTMS), U15.18 (SCK_RTSN)
/ELRS/UART0_RX: U3.78 (GPIO1), U13.27 (U0RXD)
/ELRS/UART0_TX: U3.77 (GPIO0), U13.28 (U0TXD)
/ELRS/WIFI: AE1.1 (ANT_1), U13.1 (LNA_IN)
/ELRS/XTAL_N: C67.1, U13.29 (XTAL_N), X2.3
/ELRS/XTAL_P: L4.2, U13.30 (XTAL_P)
/ESC1/AH: U4.20 (PA10), U5.22 (HIN1)
/ESC1/AL: U4.15 (PB1), U5.1 (LIN1)
/ESC1/BH: U4.19 (PA9), U5.23 (HIN2)
/ESC1/BL: U4.14 (PB0), U5.2 (LIN2)
/ESC1/CH: U4.18 (PA8), U5.24 (HIN3)
/ESC1/CL: U4.13 (PA7), U5.3 (LIN3)
/ESC1/FBA: R35.1, R36.2, R37.2, U4.6 (PA0)
/ESC1/FBB: R38.2, R39.2, R40.2, U4.10 (PA4)
/ESC1/FBC: R41.2, R42.2, R43.2, U4.11 (PA5)
/ESC1/FBCOMMON: R35.2, R38.1, R41.1, U4.7 (PA1)
/ESC1/GHA: R26.1, U5.19 (HO1)
/ESC1/GHB: R31.1, U5.16 (HO2)
/ESC1/GHC: R33.1, U5.13 (HO3)
/ESC1/GLA: R27.1, U5.11 (LO1)
/ESC1/GLB: R32.1, U5.10 (LO2)
/ESC1/GLC: R34.1, U5.9 (LO3)
/ESC1/MotorA: C48.1, J40.1 (Pin_1_1), Q4.1 (S), Q5.3 (D), R37.1, U5.18 (VS1)
/ESC1/MotorB: C49.1, J42.1 (Pin_1_1), Q6.1 (S), Q7.3 (D), R40.1, U5.15 (VS2)
/ESC1/MotorC: C50.1, J43.1 (Pin_1_1), Q8.1 (S), Q9.3 (D), R43.1, U5.12 (VS3)
/ESC1/dshot: R30.1, U3.39 (GPIO31)
/ESC2/AH: U16.20 (PA10), U17.22 (HIN1)
/ESC2/AL: U16.15 (PB1), U17.1 (LIN1)
/ESC2/BH: U16.19 (PA9), U17.23 (HIN2)
/ESC2/BL: U16.14 (PB0), U17.2 (LIN2)
/ESC2/CH: U16.18 (PA8), U17.24 (HIN3)
/ESC2/CL: U16.13 (PA7), U17.3 (LIN3)
/ESC2/FBA: R68.1, R69.2, R70.2, U16.6 (PA0)
/ESC2/FBB: R71.2, R72.2, R73.2, U16.10 (PA4)
/ESC2/FBC: R74.2, R75.2, R76.2, U16.11 (PA5)
/ESC2/FBCOMMON: R68.2, R71.1, R74.1, U16.7 (PA1)
/ESC2/GHA: R59.1, U17.19 (HO1)
/ESC2/GHB: R64.1, U17.16 (HO2)
/ESC2/GHC: R66.1, U17.13 (HO3)
/ESC2/GLA: R60.1, U17.11 (LO1)
/ESC2/GLB: R65.1, U17.10 (LO2)
/ESC2/GLC: R67.1, U17.9 (LO3)
/ESC2/MotorA: C88.1, J44.1 (Pin_1_1), Q11.1 (S), Q12.3 (D), R70.1, U17.18 (VS1)
/ESC2/MotorB: C89.1, J45.1 (Pin_1_1), Q13.1 (S), Q14.3 (D), R73.1, U17.15 (VS2)
/ESC2/MotorC: C90.1, J46.1 (Pin_1_1), Q15.1 (S), Q16.3 (D), R76.1, U17.12 (VS3)
/ESC2/dshot: R63.1, U3.38 (GPIO30)
/ESC3/AH: U18.20 (PA10), U19.22 (HIN1)
/ESC3/AL: U18.15 (PB1), U19.1 (LIN1)
/ESC3/BH: U18.19 (PA9), U19.23 (HIN2)
/ESC3/BL: U18.14 (PB0), U19.2 (LIN2)
/ESC3/CH: U18.18 (PA8), U19.24 (HIN3)
/ESC3/CL: U18.13 (PA7), U19.3 (LIN3)
/ESC3/FBA: R86.1, R87.2, R88.2, U18.6 (PA0)
/ESC3/FBB: R89.2, R90.2, R91.2, U18.10 (PA4)
/ESC3/FBC: R92.2, R93.2, R94.2, U18.11 (PA5)
/ESC3/FBCOMMON: R86.2, R89.1, R92.1, U18.7 (PA1)
/ESC3/GHA: R77.1, U19.19 (HO1)
/ESC3/GHB: R82.1, U19.16 (HO2)
/ESC3/GHC: R84.1, U19.13 (HO3)
/ESC3/GLA: R78.1, U19.11 (LO1)
/ESC3/GLB: R83.1, U19.10 (LO2)
/ESC3/GLC: R85.1, U19.9 (LO3)
/ESC3/MotorA: C95.1, J47.1 (Pin_1_1), Q17.1 (S), Q18.3 (D), R88.1, U19.18 (VS1)
/ESC3/MotorB: C96.1, J48.1 (Pin_1_1), Q19.1 (S), Q20.3 (D), R91.1, U19.15 (VS2)
/ESC3/MotorC: C97.1, J49.1 (Pin_1_1), Q21.1 (S), Q22.3 (D), R94.1, U19.12 (VS3)
/ESC3/dshot: R81.1, U3.37 (GPIO29)
/ESC4/AH: U20.20 (PA10), U21.22 (HIN1)
/ESC4/AL: U20.15 (PB1), U21.1 (LIN1)
/ESC4/BH: U20.19 (PA9), U21.23 (HIN2)
/ESC4/BL: U20.14 (PB0), U21.2 (LIN2)
/ESC4/CH: U20.18 (PA8), U21.24 (HIN3)
/ESC4/CL: U20.13 (PA7), U21.3 (LIN3)
/ESC4/FBA: R104.1, R105.2, R106.2, U20.6 (PA0)
/ESC4/FBB: R107.2, R108.2, R109.2, U20.10 (PA4)
/ESC4/FBC: R110.2, R111.2, R112.2, U20.11 (PA5)
/ESC4/FBCOMMON: R104.2, R107.1, R110.1, U20.7 (PA1)
/ESC4/GHA: R95.1, U21.19 (HO1)
/ESC4/GHB: R100.1, U21.16 (HO2)
/ESC4/GHC: R102.1, U21.13 (HO3)
/ESC4/GLA: R96.1, U21.11 (LO1)
/ESC4/GLB: R101.1, U21.10 (LO2)
/ESC4/GLC: R103.1, U21.9 (LO3)
/ESC4/MotorA: C102.1, J50.1 (Pin_1_1), Q23.1 (S), Q24.3 (D), R106.1, U21.18 (VS1)
/ESC4/MotorB: C103.1, J51.1 (Pin_1_1), Q25.1 (S), Q26.3 (D), R109.1, U21.15 (VS2)
/ESC4/MotorC: C104.1, J52.1 (Pin_1_1), Q27.1 (S), Q28.3 (D), R112.1, U21.12 (VS3)
/ESC4/dshot: R99.1, U3.36 (GPIO28)
/IMU/GYRO_CS: R14.1, U3.13 (GPIO14), U6.12 (CS)
/IMU/GYRO_INT: U3.12 (GPIO13), U6.4 (INT1)
/IMU/SPI0.CLKIN: U3.14 (GPIO15), U6.9 (INT2)
/IMU/SPI0.MISO: U3.20 (GPIO20), U6.1 (SDO/SA0)
/IMU/SPI0.MOSI: U3.19 (GPIO19), U6.14 (SDA)
/IMU/SPI0.SCK: U3.18 (GPIO18), U6.13 (SCL)
/OSD/OSD_EN: U3.2 (GPIO5), U22.6 (S)
/OSD/OSD_LVL: R114.2, R115.1, R116.2, U22.1 (B2)
/OSD/OSD_SYNC: U3.3 (GPIO6), U24.1 (OUT)
/OSD/OSD_W: R114.1, U3.1 (GPIO4)
/OSD/VIDEO_IN: J22.1 (Pin_1_1), R113.1, R117.2, U22.3 (B1)
/OSD/VIDEO_OUT: J23.1 (Pin_1_1), R120.2
/OSD/VID_DC: C108.2, D10.1 (C), U24.3 (IN+)
/OSD/VID_FILT: C106.1, C108.1, R117.1
/PADS/BUZZER-: J13.1 (Pin_1_1), Q2.3 (D)
/PADS/DIGITAL_RX: J34.1 (Pin_1_1), U3.22 (GPIO22), U12.4
/PADS/DIGITAL_TX: J33.1 (Pin_1_1), U3.21 (GPIO21), U12.3
/PADS/I2C_SCL: J7.1 (Pin_1_1), R16.2, U3.17 (GPIO17)
/PADS/I2C_SDA: J10.1 (Pin_1_1), R17.1, U3.16 (GPIO16)
/PADS/LED_STRIP: J6.1 (Pin_1_1), R25.2
/PADS/PIOUART0_RX: J29.1 (Pin_1_1), U3.80 (GPIO3)
/PADS/PIOUART0_TX: J28.1 (Pin_1_1), U3.79 (GPIO2)
/PADS/PIOUART1_RX: J39.1 (Pin_1_1), U3.28 (GPIO27)
/PADS/PIOUART1_TX: J37.1 (Pin_1_1), U3.27 (GPIO26)
/PADS/SBUS: J38.1 (Pin_1_1), R18.2, U12.6
/POWER/1.8V_PG: Q10.1 (G), R52.1, U10.4 (PG)
/POWER/10V_ENABLE: U3.9 (GPIO11), U7.5 (EN)
/RP2350/ADC_VBAT: C27.2, R2.2, R3.2, U3.52 (GPIO41_ADC1)
/RP2350/BEEPER: R19.2, U3.4 (GPIO7)
/RP2350/D+: D1.6, R12.2
/RP2350/D+_C: D1.1, USB1.A6 (DP1), USB1.B6 (DP2)
/RP2350/D-: D1.4, R11.1
/RP2350/D-_C: D1.3, USB1.A7 (DN1), USB1.B7 (DN2)
/RP2350/LED0: R15.1, U3.11 (GPIO12)
/RP2350/LED_STRIP_L: Q3.2 (S), R21.2, U3.23 (GPIO23)
/RP2350/SBUS_INVERT: Q1.3 (D), R23.1, U3.7 (GPIO9)
/RP2350/XIN: C29.2, U3.30 (XIN), X1.1
/RP2350/XOUT: R6.1, U3.31 (XOUT)
GND: AE2.1, AE2.2, C1.2, C2.2, C3.2, C4.2, C5.2, C6.2, C7.2, C8.2, C9.2, C10.2, C11.2, C12.2, C13.2, C14.2, C15.2, C16.2, C17.2, C18.2, C19.2, C20.2, C21.2, C22.2, C23.2, C24.2, C25.2, C26.2, C27.1, C28.2, C29.1, C30.2, C31.2, C32.2, C33.1, C34.2, C35.2, C36.2, C38.2, C39.2, C40.2, C41.2, C42.2, C43.1, C44.2, C45.2, C46.2, C47.2, C51.2, C52.2, C53.2, C54.2, C55.2, C58.2, C59.2, C60.2, C61.2, C62.2, C63.2, C64.2, C65.2, C66.2, C67.2, C68.2, C69.2, C70.2, C71.2, C72.2, C73.2, C74.2, C75.2, C76.2, C77.2, C78.2, C79.2, C80.2, C81.2, C82.2, C84.2, C85.2, C86.2, C87.2, C91.2, C92.2, C93.2, C94.2, C98.2, C99.2, C100.2, C101.2, C105.2, C106.2, C107.2, C109.2, C110.2, C111.2, Card1.6 (VSS), Card1.9, Card1.10, D1.2, D2.1 (K), D4.1 (K), D5.1 (K), D6.2 (A), D7.1 (K), D9.3 (GND), D10.2 (A), FL1.2 (GND), FL1.4 (GND), J4.1 (Pin_1_1), J18.1 (Pin_1_1), J19.1 (Pin_1_1), J24.1 (Pin_1_1), J27.1 (Pin_1_1), J31.1 (Pin_1_1), J35.1 (Pin_1_1), J53.1 (Pin_1_1), OSC1.1 (GND), OSC1.2 (GND), Q1.2 (S), Q2.2 (S), Q5.1 (S), Q7.1 (S), Q9.1 (S), Q10.2 (S), Q12.1 (S), Q14.1 (S), Q16.1 (S), Q18.1 (S), Q20.1 (S), Q22.1 (S), Q24.1 (S), Q26.1 (S), Q28.1 (S), R3.1, R4.1, R5.1, R20.1, R22.1, R29.2, R36.1, R39.1, R42.1, R45.2, R47.2, R49.2, R62.2, R69.1, R72.1, R75.1, R80.2, R87.1, R90.1, R93.1, R98.2, R105.1, R108.1, R111.1, R113.2, R116.1, R118.1, U1.1 (REF), U1.2 (GND), U2.1, U3.62 (VREG_PGND), U3.81 (GND), U4.16 (VSS), U4.29 (VSS), U5.6 (COM), U5.25 (COM), U6.2 (SDx/AH1/Qvar1), U6.3 (SCx/AH2/Qvar2), U6.6 (GND), U6.7 (GND), U7.1 (GND), U8.1 (GND), U9.1 (GND), U10.3 (GND), U10.7 (EP), U11.3 (GND), U11.5 (PG), U11.7 (EP), U12.2, U12.5, U12.7, U12.8, U13.33 (EP), U14.2 (GND), U14.5 (EP), U15.5 (GND), U15.13 (GND), U15.20 (GND), U15.21 (GND), U15.23 (GND), U15.24 (GND), U15.25 (EP), U16.16 (VSS), U16.29 (VSS), U17.6 (COM), U17.25 (COM), U18.16 (VSS), U18.29 (VSS), U19.6 (COM), U19.25 (COM), U20.16 (VSS), U20.29 (VSS), U21.6 (COM), U21.25 (COM), U22.2 (GND), U23.3 (V-), U24.2 (GND), U24.4 (IN-), USB1.0 (EH), USB1.A1 (GND), USB1.A12 (GND), X1.2 (GND), X1.4 (GND), X2.2 (GND), X2.4 (GND)
unnamed: C33.2, R6.2, X1.3
unnamed: C65.1, L4.1, X2.1
unnamed: D2.2 (A), R15.2
unnamed: D4.2 (A), R50.2
unnamed: D5.2 (A), R51.2
unnamed: D7.2 (A), R53.2
unnamed: D8.1 (K), R54.1
unnamed: FL1.1 (IN), U15.22 (RFIO)
unnamed: AE2.3, FL1.3 (OUT)
unnamed: C83.1, OSC1.3 (Out_Put)
unnamed: Q1.1 (G), R18.1, R20.2
unnamed: Q2.1 (G), R19.1, R22.2
unnamed: Q3.3 (D), R24.2, R25.1
unnamed: Q4.2 (G), R26.2
unnamed: Q5.2 (G), R27.2
unnamed: Q6.2 (G), R31.2
unnamed: Q7.2 (G), R32.2
unnamed: Q8.2 (G), R33.2
unnamed: Q9.2 (G), R34.2
unnamed: Q10.3 (D), R54.2
unnamed: Q11.2 (G), R59.2
unnamed: Q12.2 (G), R60.2
unnamed: Q13.2 (G), R64.2
unnamed: Q14.2 (G), R65.2
unnamed: Q15.2 (G), R66.2
unnamed: Q16.2 (G), R67.2
unnamed: Q17.2 (G), R77.2
unnamed: Q18.2 (G), R78.2
unnamed: Q19.2 (G), R82.2
unnamed: Q20.2 (G), R83.2
unnamed: Q21.2 (G), R84.2
unnamed: Q22.2 (G), R85.2
unnamed: Q23.2 (G), R95.2
unnamed: Q24.2 (G), R96.2
unnamed: Q25.2 (G), R100.2
unnamed: Q26.2 (G), R101.2
unnamed: Q27.2 (G), R102.2
unnamed: Q28.2 (G), R103.2
unnamed: R10.1, U2.2
unnamed: R1.2, U1.6 (OUT)
unnamed: C42.1, R8.2, U3.59 (ADC_AVDD)
unnamed: R10.2, U3.75 (QSPI_SS)
unnamed: C43.2, R9.2, U3.35 (RUN)
unnamed: R11.2, U3.66 (USB_DM)
unnamed: R12.1, U3.67 (USB_DP)
unnamed: C44.1, R13.2, U3.61 (VREG_AVDD)
unnamed: L1.2, U3.63 (VREG_LX)
unnamed: R29.1, U4.1 (BOOT0)
unnamed: C47.1, R28.1, U4.4 (NRST)
unnamed: TP1.1 (1_1), U4.21 (PA13)
unnamed: TP2.1 (1_1), U4.22 (PA14)
unnamed: R30.2, U4.25 (PB4)
unnamed: FB1.2, U4.5 (VDDA)
unnamed: C48.2, U5.20 (VB1)
unnamed: C49.2, U5.17 (VB2)
unnamed: C50.2, U5.14 (VB3)
unnamed: C56.2, U7.6 (CB)
unnamed: R46.1, R47.1, U7.4 (FB)
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

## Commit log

2026-06-01 Initial commit: fork OpenAIO into OpenAIO-Whoop variant
    Duplicated from sibling OpenAIO repo (toothpick class). KiCad project
    files renamed OpenAIO.* -> OpenAIO-Whoop.*; .kicad_pro filename
    self-references updated. Design content inherited verbatim, not yet
    adapted for whoop class.
    [OpenAIO-Whoop.kicad_pcb, OpenAIO-Whoop.kicad_sch, blackbox.kicad_sch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]
2026-06-06 chore: untrack CLAUDE.md — local-only agent context, never on git
2026-06-12 checkpoint: Bluejay/BLHeli_S part imports + ESC rework notes
    EFM8BB51F16G (C6547511), AGM310MAP (C5184858), BY25Q64ESCIG (C50176394)
    imported into libs/lib.kicad_sym + lib.pretty + lib.3dshapes.
    BLHELI_S_ESC_NOTES.md documents gate-drive research (1S direct drive vs
    2S level-shift requirement) and open design decisions.
    [OpenAIO-Whoop.kicad_sch, blackbox.kicad_sch, elrs.kicad_sch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]
2026-06-12 Restructure: move KiCad project under hardware/ (family convention)
    [OpenAIO-Whoop.kicad_pcb, OpenAIO-Whoop.kicad_sch, blackbox.kicad_sch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]
2026-06-12 Whoop setup: restructure, import current FC/RX sheets, Bluejay libs, research docs
    - KiCad project moved under hardware/ (family convention)
    - FC sheets <- OpenFC-Lite-Mini rev2 (osd dropped: digital-only, root never
    referenced it); ELRS sheet <- OpenRX-Lite; orphaned esc_main deleted;
    esc_channel x4 kept as inherited placeholder pending Bluejay redraw
    - Libraries replaced: lib (Lite-Mini), components/4in1ESC (4in1-mini donors),
    OpenRX-Shared (3D paths rewritten project-local via pcbnew API), new 'whoop'
    lib re-imported fresh via easyeda2kicad (EFM8BB51F16G, AGM310MAP, BY25Q64)
    - sym-lib-table duplicate stale iCloud OpenRX-Shared entries fixed
    - datasheets/ assembled (FC/ESC/ELRS); s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
    [blackbox.kicad_sch, elrs.kicad_sch, esc_main.kicad_sch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]
2026-06-12 ESC: lock no-gate-driver topology, adopt AGM314MAP, resolve 1.8V LDO
    - Direct EFM8 GPIO drive only (board space) -> complementary P+N per
    phase; 1S clean, 2S needs 2N7002 level shift per phase; dual-N 12A
    tier ruled out. Honest rating ~6-8A/phase.
    - AGM314MAP (C17701056) imported into whoop lib: pinout-identical
    drop-in for AGM310MAP, better dies, 3k stock, $0.074. Datasheet local.
    - NCV8187 replacement decided: LP5912-1.8DRVR (C2876234), same 2x2
    WSON-6 land pattern as existing LP5912-3.3, keeps PG. Consign reel.
    - ESC_DESIGN.md: teardown findings (CrazyBee EGX87C direct-drive N+P,
    BetaFPV SiZ322DT dual-N EOL, NBD double-NMOS), second sources, caveats.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
2026-06-12 Adopt TPS7A2018 as 1.8V gyro LDO; import into whoop lib
2026-06-12 ESC power stage: DMC1229UFDB-7 (2x2 U-DFN2020-6) for whoop board
    Stan: 3.3x3.3 too big for the whoop; AGM314MAP re-earmarked for the
    AM32 toothpick AIO. Full <=2.2mm LCSC sweep found exactly one power-
    class complementary N+P family at 2x2: Diodes DMCxxxxUFDB. Primary
    DMC1229UFDB-7 (C443653): N 29/P 61 mOhm @4.5V, spec'd to 1.8V gate,
    ~2.5A cont/5A burst per phase, smaller + thermally better than the
    EGX87C-class parts on commercial 5A whoops. 12V Vds caveat noted.
    Discrete fallback AON2406+YJQ1216A (2x headroom) documented.
    Symbol/footprint imported, datasheet local.
2026-06-12 FET sweep round 2: SiA527DJ is the 2x2 dual ceiling; discrete pair documented
    Deeper search incl. DigiKey/Vishay/onsemi/Nexperia/8-lead 2x2 packages.
    No complementary dual <=2.3mm beats N29/P41 (SiA527DJ, spec'd to 1.5V
    gate, LCSC+DK dual-sourced). LFPAK22 is N-only; no Chinese 2x2-8L
    duals exist. Discrete AON2406+YJQ1216A pair halves conduction loss at
    2x placements. SiA527DJ + pair imported into whoop lib; dual-vs-pair
    left as Stan's layout call. DMC1229UFDB demoted to fallback.
2026-06-12 ESC FET: XR8G02M (Stan's find) is new primary — verified vs datasheet
    XNRUSEMI XR8G02M C42457203, DFN2020-8 2x2: N 15/P 25 mOhm max @4.5V,
    spec'd to 2.5V, 20V, 8A/32A, $0.04. Beats SiA527DJ and DMC1229UFDB on
    every electrical axis; missed by sweeps due to LCSC miscategorization.
    Supply caveat: 80 pcs live, single-source -> reel-order up front.
    Honest spec target documented: ~8A cont/15-20A burst per motor.
    Package allocation: 2x2 whoop / 3.3x3.3 toothpick+Lite-tier.
2026-06-12 Adopt W25Q128JV blackbox flash + ESP8685 RX option; AGM210MAP verified
    BetaFPV Air65 II observations (Stan) close the architecture question:
    their current 12A/18A board is AGM210MAP complementary P+N with GPIO
    direct drive — same topology as ours. Datasheet verified: 3.3x3.3,
    20V (not 25V as listed), N 10/P 13 typ — supersedes AGM310/314 for
    the mid-tier 2-3S boards, 10.6k stock. 2022 board's dual-N used
    discrete bootstrap drive (3 parts/phase) — rejected for space.
    - W25Q128JVPIQ (C190862, WSON 5x6, 16MB) replaces dead BY25Q64
    - ESP8685H4 (C4944062, QFN-28 4x4) as RX MCU density option
    - diode-OR 5V selection noted as TPS2116 alternative (BetaFPV pattern)
    All imported into whoop lib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
2026-08-04 chore: wire shared Incutec KiCad library
    Adds incutec-hw/KiCad-Library as submodule at libs/KiCad-Library, pinned
    to the feat/complete-library build. Project lib tables gain the Incutec
    sym+fp entries via ${KIPRJMOD} relative paths. Existing local libraries
    untouched (frozen, see the library repo MANIFEST).
2026-08-04 chore: bump KiCad-Library submodule pin
2026-08-05 docs: adopt OpenDrone repo standard
    README rewritten to the family layout (overview, Status, Specifications,
    Repository layout, Design entry points, Build and export, Manufacturing,
    Contributing, License). Deep detail relocated to hardware/docs/DESIGN.md.
    docs/ moved to hardware/docs/. CONTRIBUTING.md, AGENTS.md, CHANGELOG.md
    added. Stale facts fixed: Incutec submodule documented, ESC power stage
    and blackbox flash decisions reflected, whoop library paths corrected.
    Depersonalized, legacy repo names purged from prose.
2026-08-05 Fix verification findings: en dashes and old ESC slug in ESC_DESIGN.md
    Replace 24 en dash range separators with plain hyphens and update
    OpenESC_20X20 references to the OpenESC-20x20 slug.
2026-08-06 Rewrite CONTRIBUTING for humans: file locking, render proof, sign-off
    KiCad files cannot be merged, so the doc now leads with claiming files via
    git lfs lock and issue-first discussion, the convention used by LumenPnP and
    Ultimate Hacking Keyboard. Adds .gitattributes marking design files lockable.
    Drops the internal documentation-style rule that meant nothing to contributors.
2026-08-06 Fix contradictions and duplicated information in the docs
    ESC_DESIGN.md carried a superseded BLHeli_S / AGM310MAP / "maybe 4S" framing in
    its header while contradicting itself further down. Restructured it into a
    research doc under the decisions that are actually locked: Bluejay on EFM8BB51,
    XR8G02M 2x2 complementary P+N, no gate-driver IC, 1S/2S only. AGM310MAP and
    AGM314MAP move under an explicit superseded heading, AGM210MAP replaces
    AGM314MAP as the mid-tier pick, and its ceiling is 2-3S to match the 20 V part.
    Other contradictions fixed:
    - BY25Q64 (64 Mbit) marked superseded by W25Q128JVPIQ (128 Mbit / 16 MB), which
    is the symbol actually in whoop.kicad_sym.
    - MARKET-RESEARCH: 12 A i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
2026-08-06 Local libraries are the working default again
    New parts go into this repo's local libraries. KiCad-Library becomes a mirror
    of parts we already use or stock, worth checking first because a hit means we
    have sourced it before. Promotion into it is a separate step.
